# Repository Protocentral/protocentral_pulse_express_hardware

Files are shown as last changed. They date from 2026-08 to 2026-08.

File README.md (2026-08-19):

# ProtoCentral Pulse Express — Hardware

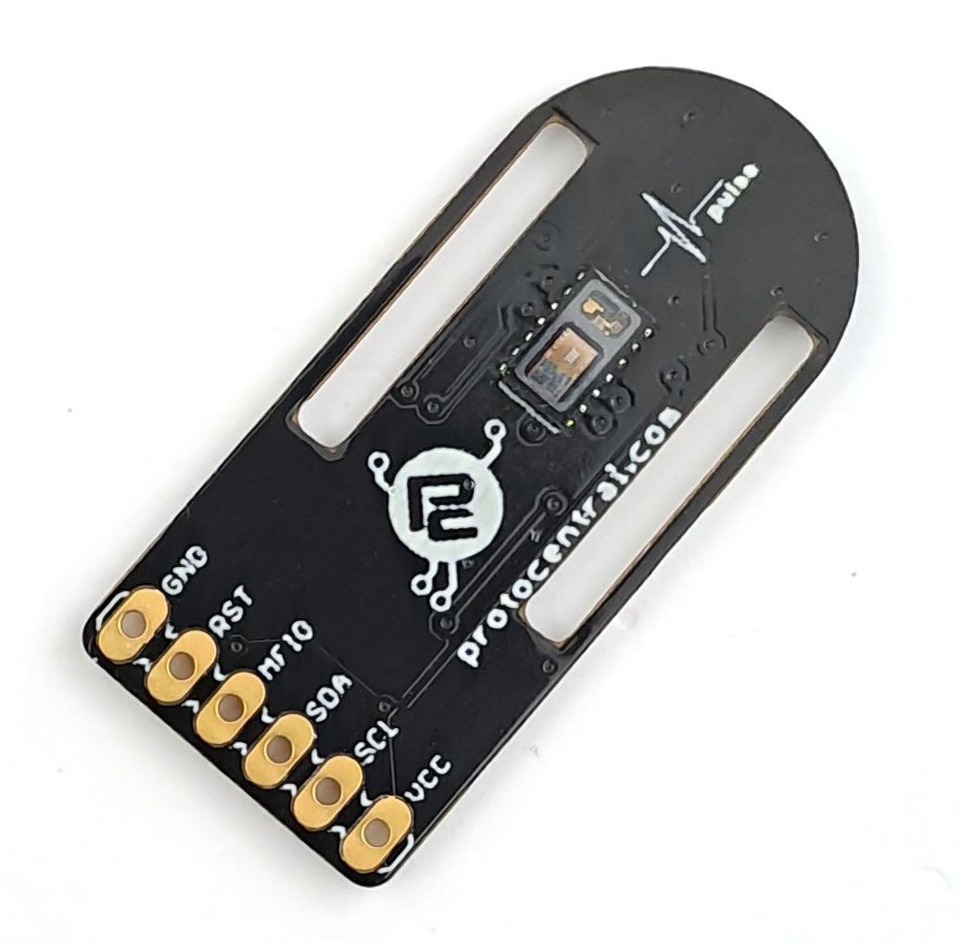
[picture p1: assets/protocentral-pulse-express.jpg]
ProtoCentral Pulse Express Pulse-Ox & Heart Rate Sensor


Open-source hardware design files for the **ProtoCentral Pulse Express** pulse-oximetry / heart-rate breakout — pairing the [Maxim MAX30102](https://www.analog.com/en/products/max30102.html) optical sensor with the [Maxim MAX32664D](https://www.analog.com/en/products/max32664.html) biometric sensor hub.

Unlike our [Pulse](https://github.com/Protocentral/protocentral_pulse_hardware) board, which streams raw PPG for the host to process, Pulse Express runs Maxim's algorithms on the MAX32664D hub itself and returns computed heart rate, SpO₂, and blood-pressure-trend estimates over I²C. That offloads the signal processing from your MCU at the cost of visibility into the raw signal.

## Links

| | |
|---|---|
| 🛒 Product page | https://protocentral.com/product/pulse-express-pulse-ox-heart-rate-sensor-with-max32664/ |
| 💻 Arduino library | https://github.com/Protocentral/protocentral-pulse-express |
| 📄 Sensor hub datasheet (Analog Devices / Maxim) | https://www.analog.com/media/en/technical-documentation/data-sheets/MAX32664.pdf |
| 📄 Optical sensor datasheet | https://www.analog.com/media/en/technical-documentation/data-sheets/MAX30102.pdf |

## Specifications

- **Sensor hub:** Maxim MAX32664GTGD+ (MAX32664D variant) with 32.768 kHz crystal
- **Optical sensor:** Maxim MAX30102 — red (660 nm) + IR (880 nm) LEDs, photodiode, and AFE
- **Output:** computed heart rate, SpO₂, and blood-pressure trend from the on-hub algorithms
- **Interface:** I²C, via 2× TXS0102 bidirectional level translators
- **Connector:** 6-pin 0.1″ header
- **Supply:** onboard AP2112K-3.3 V and AP2112K-1.8 V LDOs
- **Board:** 36.0 × 17.5 mm, 2-layer

## Revisions

| Revision | Design files | Notes |
|---|---|---|
| **v3** (current) | [`hardware/`](hardware/) | KiCad 10 |
| earlier | [`protocentral-pulse-express/hardware/`](https://github.com/Protocentral/protocentral-pulse-express/tree/master/hardware) | Eagle; retained in the Arduino library repository so existing links keep working |

## Repository layout

| Folder | Contents |
|---|---|
| [`hardware/`](hardware/) | KiCad project (schematic + PCB layout) and the exported [schematic PDF](hardware/protocentral-pulse-express-v3-schematic.pdf) |

## Important notice

This device is intended for research, education, and evaluation use only. It is **not** a medical diagnostic instrument and is not FDA, CE, or FCC approved for consumer use. The blood-pressure-trend output of the MAX32664D requires per-user calibration and is not a substitute for a validated blood-pressure monitor.

## License

The hardware design files in this repository are licensed under the **CERN Open Hardware Licence Version 2 – Permissive (CERN-OHL-P v2)**. See [LICENSE](LICENSE).

The accompanying firmware/library (in the separate [protocentral-pulse-express](https://github.com/Protocentral/protocentral-pulse-express) repository) is licensed under the MIT License.

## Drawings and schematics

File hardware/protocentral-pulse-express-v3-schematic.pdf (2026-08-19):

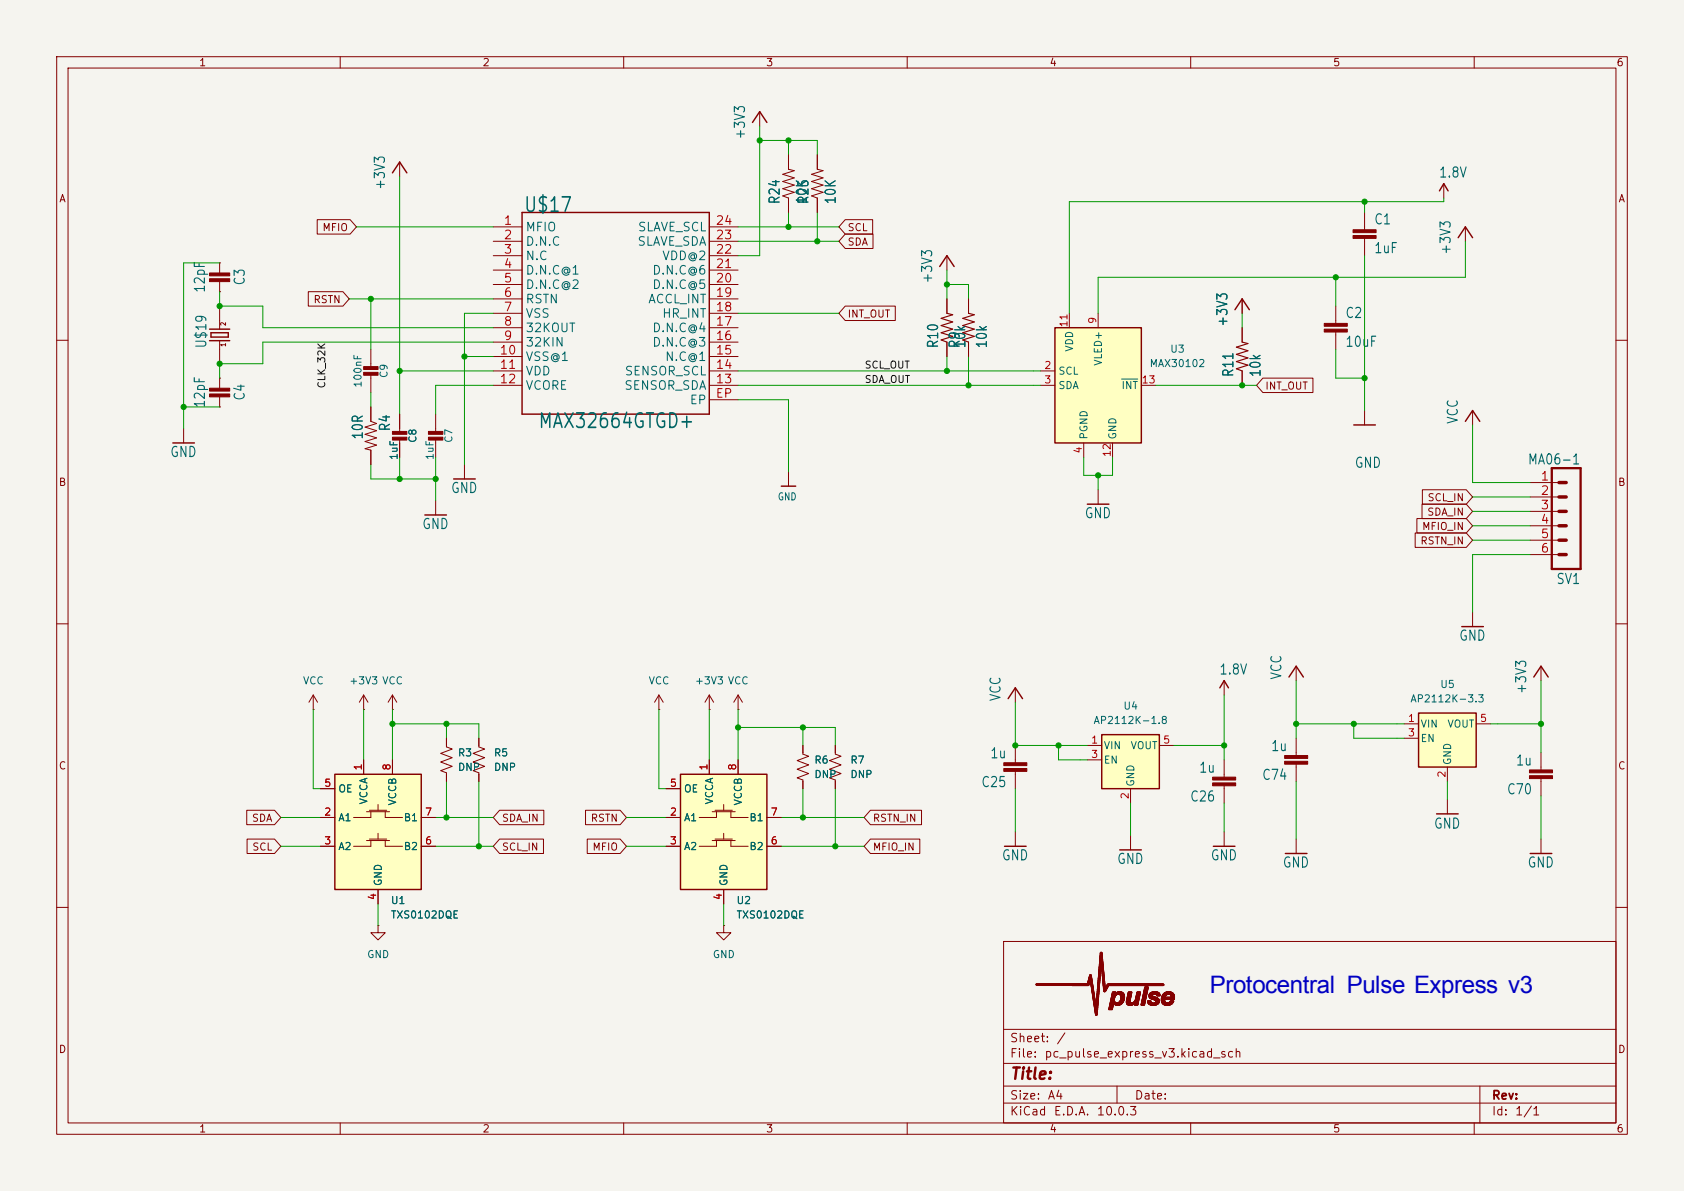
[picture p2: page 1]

Size: A4 | Rev:
KiCad E.D.A. 10.0.3 | Id: 1/1

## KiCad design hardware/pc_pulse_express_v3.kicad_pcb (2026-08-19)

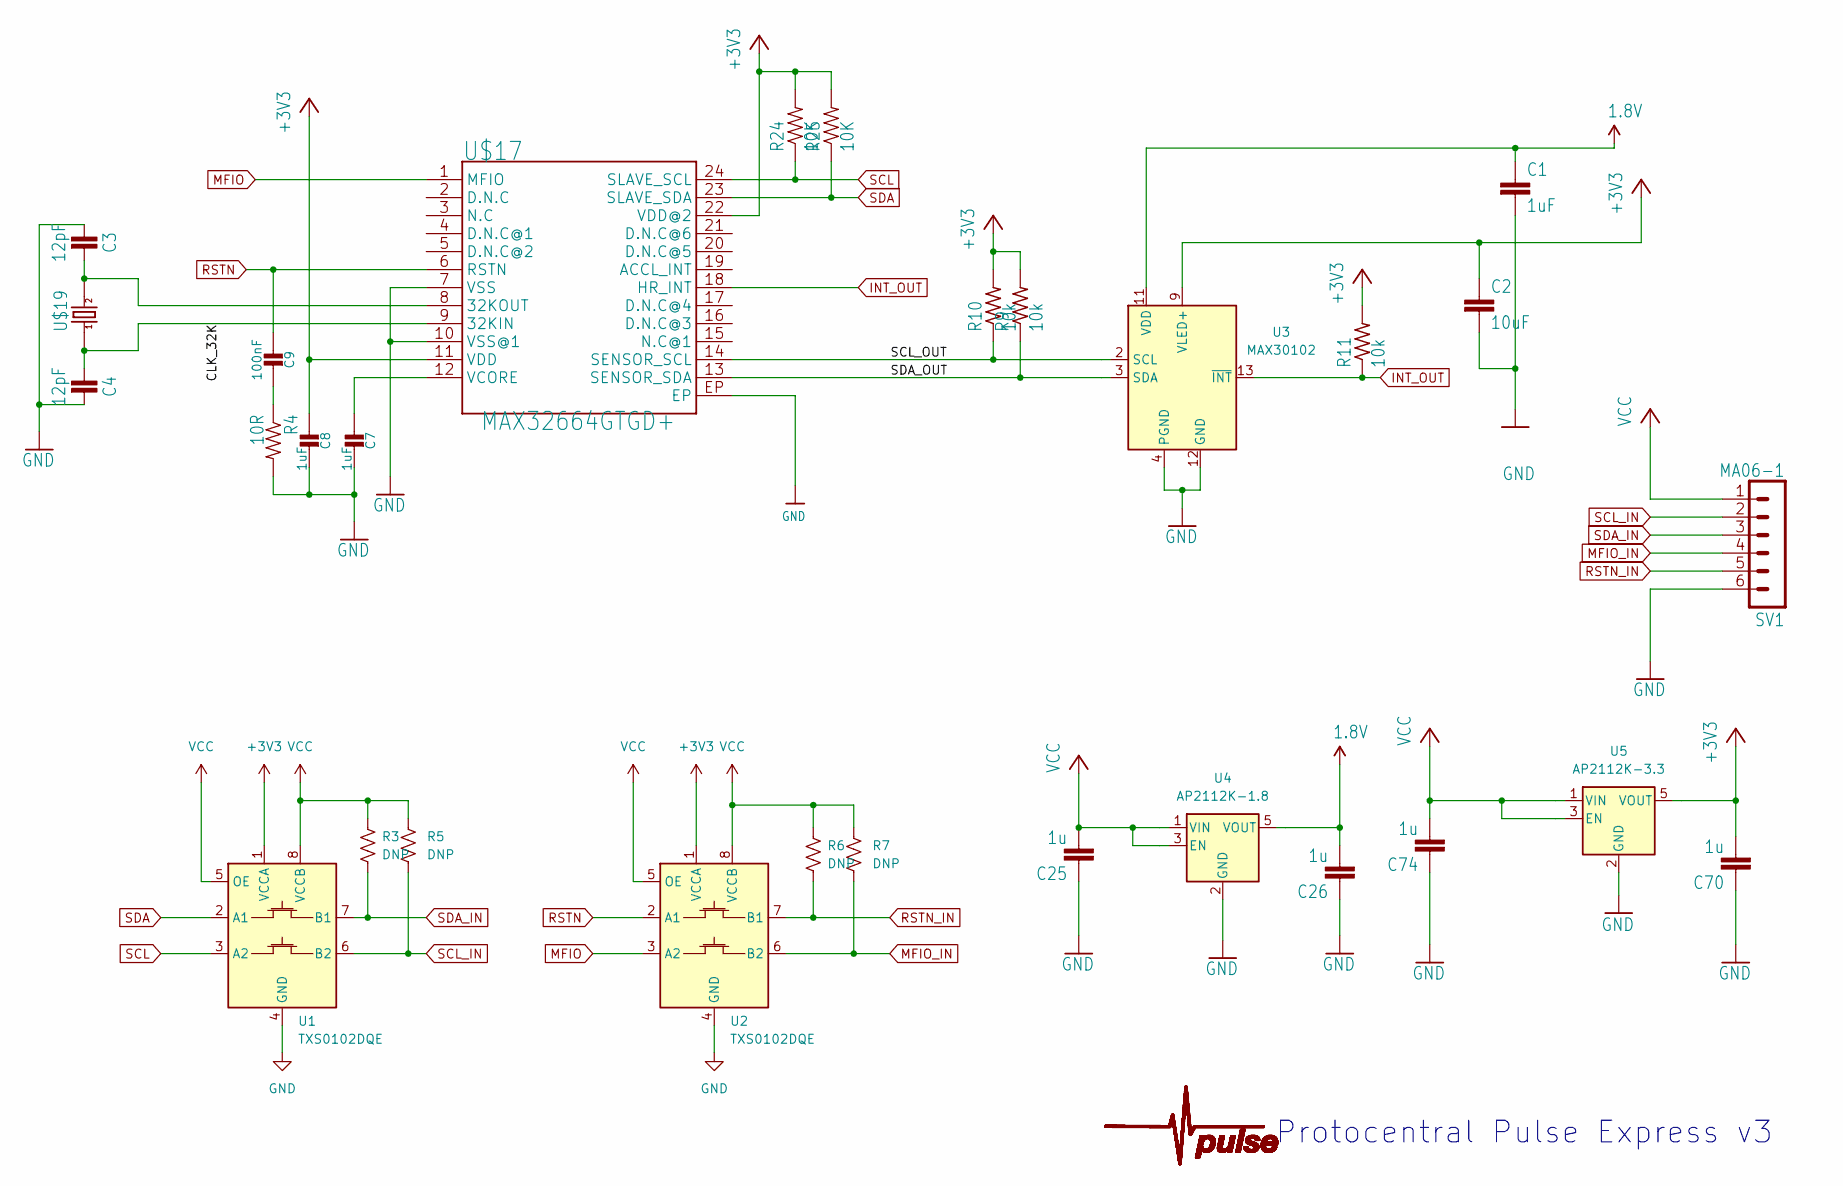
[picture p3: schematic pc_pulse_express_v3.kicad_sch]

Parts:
C1, C7, C8: 1uF; C_0402_1005Metric_Pad0.74x0.62mm_HandSolder
C2: 10uF; C_0402_1005Metric_Pad0.74x0.62mm_HandSolder
C3, C4: 12pF; C_0402_1005Metric_Pad0.74x0.62mm_HandSolder
C9: 100nF; C_0402_1005Metric_Pad0.74x0.62mm_HandSolder
C25, C26, C70, C74: 1u; C_0402_1005Metric_Pad0.74x0.62mm_HandSolder
R3, R5, R6, R7: DNP; R_0402_1005Metric_Pad0.72x0.64mm_HandSolder
R4: 10R; R_0402_1005Metric_Pad0.72x0.64mm_HandSolder
R9, R10, R11: 10k; R_0402_1005Metric_Pad0.72x0.64mm_HandSolder
R24, R25: 10K; R_0402_1005Metric_Pad0.72x0.64mm_HandSolder
SV1: MA06-1
U1, U2: TXS0102DQE; X2SON-8_1.4x1mm_P0.35mm
U3: MAX30102; Maxim_OLGA-14_3.3x5.6mm_P0.8mm
U4: AP2112K-1.8; SOT-23-5
U5: AP2112K-3.3; SOT-23-5
U$4: PULSE; PULSESMALL
U$17: MAX32664GTGD+; TQFN-24L
U$19: 520-327-12.5-34B(32.768KHZ); ECX-31B

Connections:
1.8V: C1.1, C26.2, U3.11 (VDD), U4.5 (VOUT)
+3V3: C2.1, C8.1, C70.2, R9.2, R10.2, R11.2, R24.2, R25.2, U1.1 (VCCA), U2.1 (VCCA), U3.9 (VLED+), U3.10 (VLED+), U5.5 (VOUT), U$17.11 (VDD), U$17.22 (VDD@2); also elsewhere on the board
/CLK_32K: C4.1, U$17.9 (32KIN), U$19.P$1 (1); also elsewhere on the board
/SCL_OUT: R10.1, U3.2 (SCL), U$17.14 (SENSOR_SCL)
/SDA_OUT: R9.1, U3.3 (SDA), U$17.13 (SENSOR_SDA)
GND: C1.2, C2.2, C3.1, C4.2, C7.2, C8.2, C25.1, C26.1, C70.1, C74.1, R4.2, SV1.6, U1.4 (GND), U2.4 (GND), U3.4 (PGND), U3.12 (GND), U4.2 (GND), U5.2 (GND), U$17.7 (VSS), U$17.10 (VSS@1), U$17.EP; also elsewhere on the board
INT_OUT: R11.1, U3.13 (~INT), U$17.18 (HR_INT)
MFIO: U2.3 (A2), U$17.1 (MFIO)
MFIO_IN: R7.2, SV1.4, U2.6 (B2)
unnamed: C9.2, R4.1
unnamed: C3.2, U$17.8 (32KOUT), U$19.P$2 (2)
unnamed: C7.1, U$17.12 (VCORE)
RSTN: C9.1, U2.2 (A1), U$17.6 (RSTN)
RSTN_IN: R6.2, SV1.5, U2.7 (B1)
SCL: R24.1, U1.3 (A2), U$17.24 (SLAVE_SCL)
SCL_IN: R5.2, SV1.2, U1.6 (B2)
SDA: R25.1, U1.2 (A1), U$17.23 (SLAVE_SDA)
SDA_IN: R3.2, SV1.3, U1.7 (B1)
VCC: C25.2, C74.2, R3.1, R5.1, R6.1, R7.1, SV1.1, U1.5 (OE), U1.8 (VCCB), U2.5 (OE), U2.8 (VCCB), U4.1 (VIN), U4.3 (EN), U5.1 (VIN), U5.3 (EN)

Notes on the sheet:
Protocentral Pulse Express v3

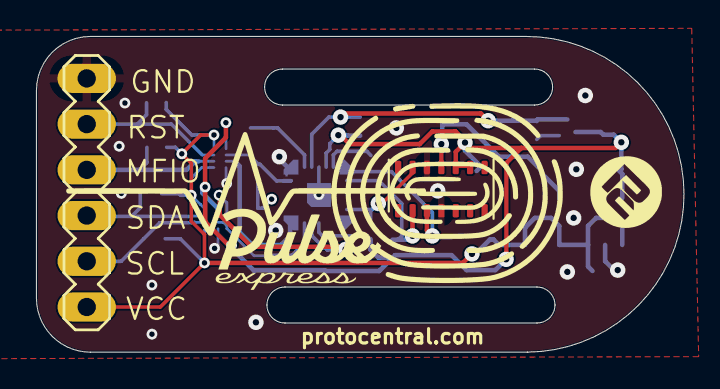
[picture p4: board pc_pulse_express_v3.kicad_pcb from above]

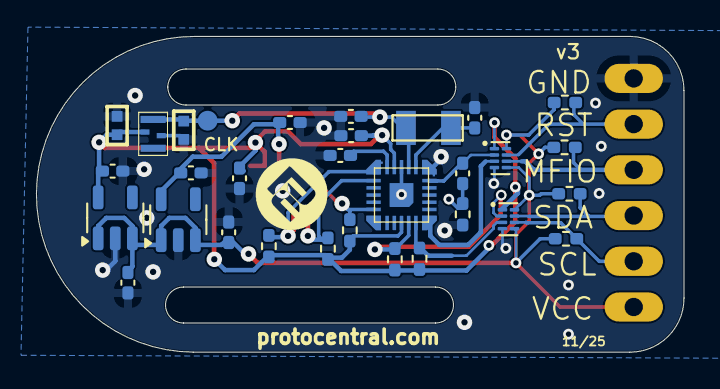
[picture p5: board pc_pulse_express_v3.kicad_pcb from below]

Board: 2 copper layers, 36.0 x 17.5 mm, 34 parts (31 on the bottom side), 19 nets.

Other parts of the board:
C14: 1uF; _0402
C15: 22pF; _0402
SWIO1: TPSQTP11R; TP11R_385
U$29: SIT1533AI-H4-DCC-32.768E; SIT1533

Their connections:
+3V3: C14.1, U$29.4 (VDD); also elsewhere on the board
/CLK_32K: C15.1, SWIO1.TP, U$29.3 (CLK); also elsewhere on the board
GND: C14.2, C15.2, U$29.2 (GND); also elsewhere on the board
